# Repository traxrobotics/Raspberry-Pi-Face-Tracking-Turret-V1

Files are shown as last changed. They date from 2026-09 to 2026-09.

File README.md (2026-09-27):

# Raspberry Pi Face Tracking Turret v1






A pan and tilt camera turret that finds your face and keeps it in the middle of the picture.
Runs on a Raspberry Pi 5 with a cheap SPI camera and two SG90 servos, all wired straight
to the Pi's header. No servo driver board, no second power supply. A Pi 4 is fine too.

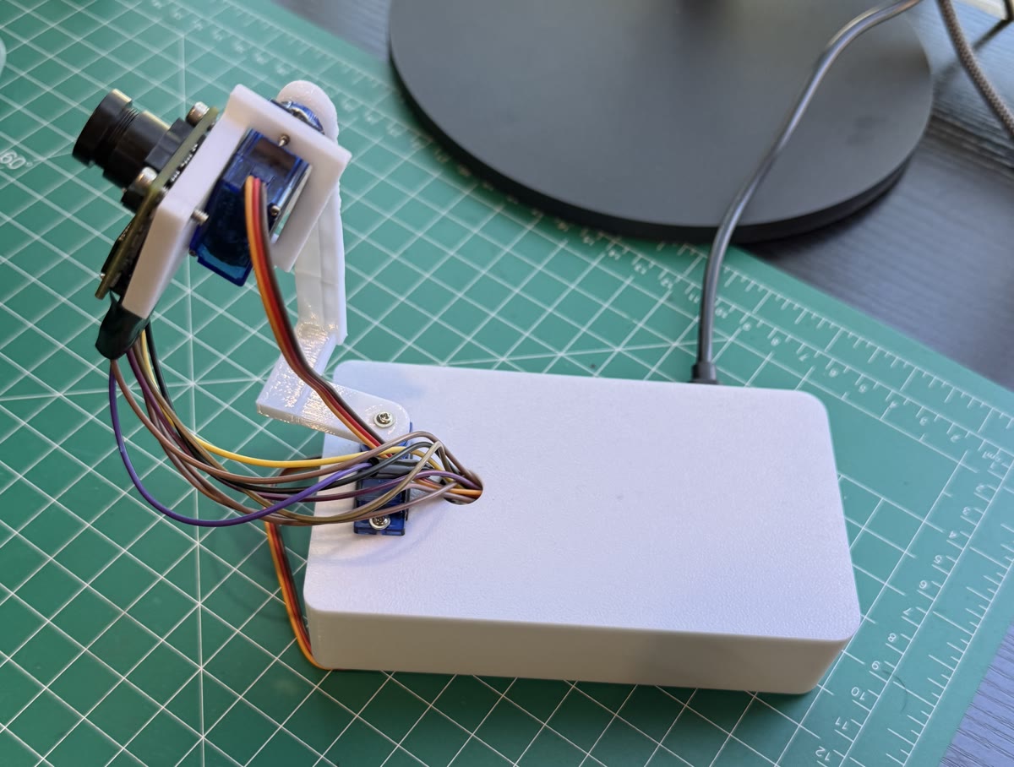
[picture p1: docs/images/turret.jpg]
The assembled turret, click to watch it tracking a face (https://www.tiktok.com/@traxrobotics/video/7688967664974302495)


The assembled turret. **[Click the photo to watch it track a face.](https://www.tiktok.com/@traxrobotics/video/7688967664974302495)**

Two clips, both on TikTok: **[building it](https://www.tiktok.com/@traxrobotics/video/7688210893309562142)**
and **[tracking a face](https://www.tiktok.com/@traxrobotics/video/7688967664974302495)**.
Both are short montages rather than tutorials, and both show the physical side
only -- no terminal, no setup steps. Those are in this README and in
[`docs/`](docs/).

<!-- A looping demo.gif at docs/images/demo.gif would play inline here;
     GitHub strips video embeds, so the photo above links out instead. -->

## Features

* **Fast, smooth tracking.** Servos run their own 100 Hz motion loop with speed and braking
  limits, so they glide instead of jerking between camera frames.
* **Aims ahead of a moving face.** It measures how fast you are moving and leads you, so it
  keeps up instead of trailing behind.
* **Chases a head that flicks out of the picture.** If your face vanishes at the edge, or while
  moving fast, or leaves a blur behind as it goes, the turret turns hard that way at once.
* **Searches when you leave.** With nobody in view it sweeps slowly side to side, first
  toward the side you walked off to, and locks back on the moment it sees a face.
* **Good face detection.** Uses YuNet (OpenCV 4.8+) or an SSD model on older OpenCV, and falls
  back to Haar only if the models are missing.
* **Fixes a sideways or upside down camera by itself**, and tells you the setting to save.
* **Live view in any browser** with the detected face boxed in green.
* **Starts on boot** as a system service, with a `turret` command to start, stop and diagnose it.
* **Plain language errors.** Every failure says which pin or setting to check.
* **Tested without hardware.** A fake camera and fake servos run the whole tracker in CI.

## Hardware

| Part | Notes |
|---|---|
| Raspberry Pi 5 | Raspberry Pi OS Bookworm or Trixie |
| ArduCAM Mini 2MP Plus (B0067) | OV2640 sensor, SPI + I2C |
| 2 × SG90 micro servos | pan and tilt |
| Pan and tilt bracket | any SG90 bracket works, or print the one in [`hardware/`](hardware/) |
| 8 × female to female jumpers | camera |
| 6 × male to female jumpers | servos |
| 1000 µF electrolytic capacitor, 10 V+ | across one servo's power, stops brownout resets |

### Printed parts

Three printable parts are in [`hardware/`](hardware/) if you would rather print the
bracket than buy one: the base, the arm, and the camera attachment. Each comes as
`.3mf` to print and `.step` to edit.

The base has no floor. That keeps the servo and wiring reachable while you build,
and lets the turret bolt onto another robot's deck instead of carrying its own
bottom plate. See [`hardware/README.md`](hardware/README.md) for print settings.

## Wiring

| Wire | Pi pin |
|---|---|
| Camera VCC | 1 (3.3 V, **never 5 V**) |
| Camera SDA / SCL | 3 / 5 |
| Camera CS | 11 (GPIO17) |
| Camera MOSI / MISO / SCK | 19 / 21 / 23 |
| Camera GND | 25 |
| Pan servo signal / 5 V / GND | 32 (GPIO12) / 2 / 34 |
| Tilt servo signal / 5 V / GND | 33 (GPIO13) / 4 / 30 |

Full diagram, reasons for each pin, and assembly order: [docs/wiring.md](docs/wiring.md).

## Quick start

On the Pi:

```bash
git clone https://github.com/traxrobotics/Raspberry-Pi-Face-Tracking-Turret-V1.git ~/turret
cd ~/turret
bash setup.sh          # packages, SPI, I2C, hardware PWM
bash install_boot.sh   # start on boot + password free 'turret' command
sudo reboot
```

After the reboot, stop the background turret so the checks can use the camera, then run them in order:

```bash
turret stop
python3 test_bus.py             # camera wiring: both lines should say OK
python3 test_capture.py         # takes snapshot.jpg and measures frame rate
python3 test_servos.py          # sweeps servos, prints PAN_DIR / TILT_DIR for config.py
python3 tracker.py --no-servos  # track without moving, open the printed address in a browser
turret start                    # track for real
```

## The `turret` command

| Command | What it does |
|---|---|
| `turret status` | is it running? |
| `turret log` | watch what it is doing (Ctrl+C stops watching, not the turret) |
| `turret stop` / `start` / `restart` | control the background service |
| `turret run` | run it in this window to see everything it prints |
| `turret boot-off` / `boot-on` | stop or resume starting on boot |
| `turret doctor` | checks every piece and says exactly what is wrong |

## Settings

Everything lives in [`config.py`](config.py). The ones you are most likely to touch:

| Setting | Default | What it does |
|---|---|---|
| `PAN_DIR`, `TILT_DIR` | from `test_servos.py` | flip if it turns away from you |
| `SERVO_SPEED` | 550 | top speed, degrees per second |
| `SERVO_ACCEL` | 4500 | how hard it speeds up and brakes |
| `CHASE` | True | turn hard toward a face that just left the picture |
| `CHASE_DEG`, `CHASE_S` | 20, 0.7 | how far past the last sighting to aim, and for how long |
| `LEAD` | 1.0 | aim ahead of a moving face, 0 turns it off |
| `SWEEP` | True | search side to side when nobody is there, False waits at center |
| `SWEEP_SPEED` | 30 | search speed, degrees per second |
| `SWEEP_MIN`, `SWEEP_MAX`, `SWEEP_TILT` | 40, 140, 90 | where it searches |
| `RETURN_AFTER_S` | 2.0 | seconds with no face before it starts searching |
| `CORRECTION` | 0.9 | lower if it swings past you |
| `SPI_SPEED_HZ` | 8 MHz | drops to 4 MHz by itself if frames fail |

Symptom by symptom tuning guide: [docs/tuning.md](docs/tuning.md).

## How it works

Three loops run at once:

1. **Camera thread** grabs JPEG frames over SPI and timestamps each one.
2. **Main loop** finds the face, works out how many degrees off center it is, checks where
   the servos were pointing when that photo was taken, and sets a new aim point, a little
   ahead of you if you are moving.
3. **Servo loop** runs 100 times a second and glides both servos toward the aim point with
   smooth acceleration.

If the face vanishes near an edge, while moving fast, or leaving a blur trail in the picture,
the turret chases: it aims past the last sighting in that direction at full speed. If that
misses, it starts sweeping that way right away.

When nobody has been seen for 2 seconds, the aim point becomes the end of a slow sweep,
and the servo loop is told to cap its speed so the camera can still spot a face mid sweep.

More detail: [docs/how-it-works.md](docs/how-it-works.md).

## Project layout

```
tracker.py        main program: detection, aiming, live view
servo.py          hardware PWM servos and the smooth motion loop
arducam.py        ArduCAM Mini 2MP Plus driver for the Pi 5 (SPI + I2C)
ov2640_regs.py    sensor register tables
config.py         every setting
test_bus.py       hardware check: camera wiring
test_capture.py   hardware check: picture and frame rate
test_servos.py    hardware check: servo range and direction
setup.sh          one time install
install_boot.sh   start on boot + turret command
turret            the turret command
doctor.sh         turret doctor
models/           face detection models
tests/            automatic tests with fake hardware (no Pi needed)
docs/             wiring, tuning, troubleshooting, internals
```

## Running the tests

No Pi needed:

```bash
pip install -r requirements-dev.txt
pytest
```

The `test_*.py` files in the top folder are hardware checks for the Pi. The automatic
tests live in `tests/` and use a fake camera and fake servos.

**One test is known to be flaky.** `test_turret_centers_on_the_face_and_settles`
fails roughly one run in four, with "turret ran away from the face". It is not
your machine and it is not a broken checkout: the fake camera produces a frame
every 30 ms while the servos run their own 100 Hz loop on the real clock, so how
far they turn between frames depends on how busy the machine is. On a loaded one
they overrun the face and the assertion fires. Re-run `pytest` and it passes.

Worth knowing rather than hiding, because it is pointing at something real: when
frames arrive slowly, the tracker overshoots. On a Pi that is fast enough to keep
the frame rate up you will not see it.

## Roadmap

* **OLED eyes.** A 0.96" SSD1306 screen showing cartoon eyes that follow your face, blink,
  and look around while the turret searches. It can share the camera's I2C bus (it sits at
  address 0x3C, the camera at 0x30). Planned, not built yet.

## Troubleshooting

Run `turret doctor` first. It checks every piece and prints the fix.
Common problems and fixes: [docs/troubleshooting.md](docs/troubleshooting.md).

## License

MIT. See [LICENSE](LICENSE). The face detection models in `models/` keep their own
licenses, listed in [NOTICE](NOTICE) and in [models/README.md](models/README.md).

## Author

Built by **Veer Sharma** ([@traxrobotics](https://www.tiktok.com/@traxrobotics)).
More projects, parts lists and code at [traxlinks.netlify.app](https://traxlinks.netlify.app).

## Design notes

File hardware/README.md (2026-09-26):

# Printed parts

Three parts make the pan and tilt stack. Everything is small, flat-ish and
prints without a heated chamber.

| Part | Carries | Files |
|---|---|---|
| `base` | the pan servo | `base.3mf`, `base.step` |
| `turret-arm` | rides the pan servo, holds the tilt servo | `turret-arm.3mf`, `turret-arm.step` |
| `camera-attachment` | the ArduCAM Mini 2MP Plus on the tilt servo | `camera-attachment.3mf`, `camera-attachment.step` |

You do not need these. The README lists "any SG90 bracket works", and that is
still true. These are here if you would rather print the exact thing in the
photos than buy a bracket.

## The base has no floor

This is deliberate, and it is the one thing worth knowing before you print.

Leaving the bottom open means you can reach the servo and the wiring while you
are working, instead of assembling blind through a hole. It also means the
turret bolts straight onto another robot's deck and uses that as its floor,
rather than carrying a redundant bottom plate of its own.

If you want it to stand on a desk by itself, print any flat plate wider than
the base and screw it on, or weigh the base down. It is not tippy, but it is
not bolted to anything either.

## Which file to use

**`.3mf` to print.** Load it straight into your slicer. These carry their units
(millimetres), so nothing arrives at 25× scale the way a bare STL sometimes does.

**`.step` to change.** STEP is solid geometry rather than a mesh, so you can open
it in Fusion, FreeCAD, Onshape or SolidWorks and actually edit it — widen the
servo pocket, move a screw hole, fit the base to your own robot. Editing a 3MF
means pushing triangles around, which you do not want to do.

There are no STL files here on purpose. 3MF does everything STL does and carries
units as well, and every current slicer reads it.

## Print settings

Standard PLA settings are fine:

| Setting | Value |
|---|---|
| Material | PLA |
| Layer height | 0.2 mm |
| Infill | 20% |
| Supports | where your slicer asks for them |

**Use PETG for the support interface if you have a multi-material setup.** PETG
does not bond well to PLA, so PETG supports snap off a PLA part cleanly and
leave a much better surface than PLA-on-PLA, which fuses and tears. This needs
an AMS, an MMU or a manual filament swap at the right layer — if you have a
single-extruder printer, just use normal PLA supports and clean them up.

Nothing here is under real load. The servos are the weak point long before the
plastic is, so there is no reason to reach for a tougher material unless the
turret is living somewhere hot.

## Assembly

Two SG90 servos and the camera, in the order in the table above: pan servo into
the base, arm onto the pan servo's horn, tilt servo into the arm, camera
attachment onto the tilt servo's horn.

Wiring is in [`../docs/wiring.md`](../docs/wiring.md). Read the 3.3 V warning at
the top of that file before you plug the camera in.

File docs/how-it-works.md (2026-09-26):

# How it works

## The camera (`arducam.py`)

The ArduCAM Mini 2MP Plus has two parts. The OV2640 sensor is set up over I2C (address 0x30).
The ArduChip stores each JPEG frame in a 384 KB buffer and hands it over on SPI.

ArduCAM's own library does not support the Pi 5, so `arducam.py` follows the same steps
using the normal Linux `spidev` and `smbus2` drivers. Chip select is driven by hand on GPIO17
so it stays low for a whole burst read. The driver cuts the real JPEG out of the buffer by
its start (`FF D8`) and end (`FF D9`) markers, because the buffer starts with a junk byte and
ends with padding. Each frame gets a timestamp for the moment the photo was taken.

## Three loops

```
 camera thread            main loop                       servo loop (100 Hz)
 ─────────────            ─────────                       ───────────────────
 take photo ──frame──▶ find face                          glide toward aim point
 timestamp it          degrees off center                 speed up, cruise, brake
 repeat                where were servos at photo time? ◀── position history
                       how fast is the face moving?
                       new aim point ─────────────────────▶ set_target
```

**Camera thread.** Pulling a frame over SPI is the slowest step. Doing it in its own thread
means the next photo is already on its way while the last one is searched, which gives more
frames per second and fresher frames. If frames keep failing at 8 MHz it drops the SPI clock
to 4 MHz by itself.

**Main loop.** The lens sees about 60° across, so a face 40 pixels off center is a known
number of degrees off. The servos keep moving while a photo is being taken and searched, so
the aim is *where the servos were when the photo was taken*, plus that angle. Using the servo
position at photo time, not the current one, is what stops it from overshooting.

**Leading a moving face.** The main loop fits a straight line through the face's position
over the last 0.4 seconds to get its speed in degrees per second. The face has already moved
on since the photo was taken, so the aim is pushed ahead by speed × (photo age + servo catch
up time), capped at 12°. Speeds under 8°/s count as sitting still, so a box that wobbles by a
pixel never causes twitching. While the servos themselves are snapping fast, their position
at photo time is too uncertain to judge speed from, so leading pauses until they slow down.

**Servo loop.** 100 times a second, each servo moves toward its aim with a trapezoid speed
profile: speed up at `SERVO_ACCEL`, cruise at `SERVO_SPEED`, and brake just in time to land
exactly on target. This keeps motion smooth even though new aim points only arrive about
12 times a second.

## Chasing a face that just left

A head moved fast enough blurs out of the picture in one or two frames. When the face
vanishes, the tracker asks three questions about its last sighting, in order:

1. **Was it moving fast?** Speed from the 0.4 s fit, or from the jump between the last two
   sightings (a sudden flick often shows up in just one frame). Over 25°/s counts.
2. **Was it near the edge?** Face center in the outer part of the picture.
3. **Did something smear away?** `motion_hint` compares a tiny 80×60 grey copy of this frame
   with the one before and finds the middle of the changed pixels. A flicked head leaves its
   blur on the side it went. Only left/right is used: the body sits below the face, so the
   changed area always leans down. If under 0.4% or over 40% of the picture changed (nothing,
   or a light/exposure change), the hint is ignored.

The first clear answer gives the direction. The turret aims `CHASE_DEG` (more if the face was
fast) past the last sighting at full speed. If nothing turns up within `CHASE_S`, it starts
sweeping that way at once instead of waiting.

To stop chases from bouncing back and forth, a chase only starts from a sighting taken
while the servos were fairly still, after the face had been tracked for at least 0.3 s, and
not within 1.5 s of the last chase. A face that vanishes from the middle with none of the
three clues (someone turning away) gets the normal wait, then the sweep.

## Searching

After `RETURN_AFTER_S` seconds with no face, the tracker switches to a sweep. It aims at one
end of the sweep (`SWEEP_MIN` or `SWEEP_MAX`), starting with the side the face was last seen
on, and asks the servo loop to cap its speed at `SWEEP_SPEED` for that move. When the servos
get within 2° of that end, it aims at the other end. Tilt holds at `SWEEP_TILT`.

The speed cap matters: at full speed the camera would smear past a face between frames.
At 30°/s and about 12 frames a second the view moves under 3° per frame, so a face is in view
for about 20 frames on every pass. The moment a face is found, the cap is lifted and normal
tracking takes over at full speed.

## Face detection

`FaceDetector` picks the best model the Pi can run:

| Detector | Needs | Notes |
|---|---|---|
| YuNet | OpenCV 4.8+ (Raspberry Pi OS Trixie) | small, fast, handles angles and dim light |
| SSD (res10) | any OpenCV 4 (Bookworm) | very reliable, a bit slower |
| Haar | nothing | last resort if `models/` is missing |

When there are several faces it sticks with the one closest to the face it was already
following, so it does not jump between people.

## Auto orientation

A face detector is always most confident about an upright face. `AutoOrient` scores the
picture as is and turned 90°, 180° and 270°, and keeps whichever it is surest about. The
servos hold still until the check passes, so they never chase an upside down face (which
would make the turret run away). Once the picture keeps passing, it checks less and less
often, down to once every 320 face frames.

## Servos (`servo.py`)

Hardware PWM through `/sys/class/pwm` at 50 Hz, 600 to 2400 µs for 0 to 180°. The PWM block's
number changes between OS versions, so it is found by name: the one at `...98000.pwm` drives
GPIO12/13. The one at `...9c000.pwm` runs the Pi 5 cooling fan and is never touched.

## Boot service

`install_boot.sh` installs a normal systemd service that runs as root (so it never trips over
permissions at boot) and restarts every 3 seconds until the camera and servos are ready. A
sudoers rule lets your user start and stop exactly that service, and nothing else, with no
password. On stop it glides both servos to center and turns the PWM off so they go limp.

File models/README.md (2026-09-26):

# Face detection models

`tracker.py` picks the best one your OpenCV can run. Keep this folder next to `tracker.py`.

| File | Model | Source | License |
|---|---|---|---|
| `face_detection_yunet_2023mar.onnx` | YuNet | [opencv/opencv_zoo](https://github.com/opencv/opencv_zoo/tree/main/models/face_detection_yunet) | MIT, Copyright (c) 2020 Shiqi Yu |
| `res10_300x300_ssd_iter_140000.caffemodel` | ResNet 10 SSD | [opencv/opencv_3rdparty](https://github.com/opencv/opencv_3rdparty/tree/dnn_samples_face_detector_20170830) | OpenCV project, see source |
| `deploy.prototxt` | SSD network definition | [opencv/opencv samples](https://github.com/opencv/opencv/tree/4.x/samples/dnn/face_detector) | OpenCV project, see source |

These files are redistributed unchanged. They are not covered by this project's MIT license.

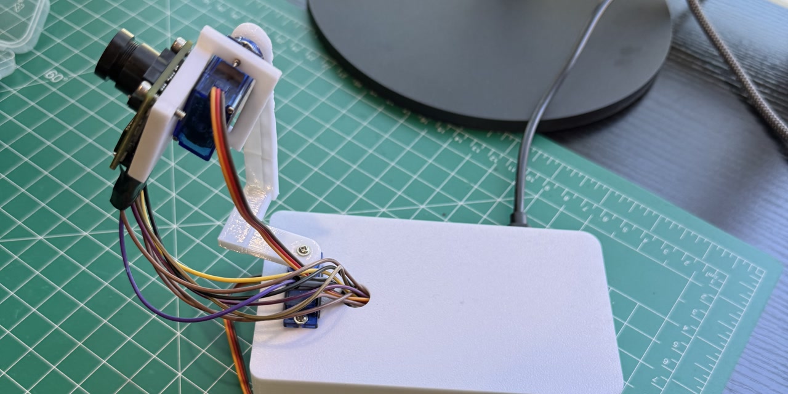
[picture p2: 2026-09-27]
docs/images/social-preview.jpg

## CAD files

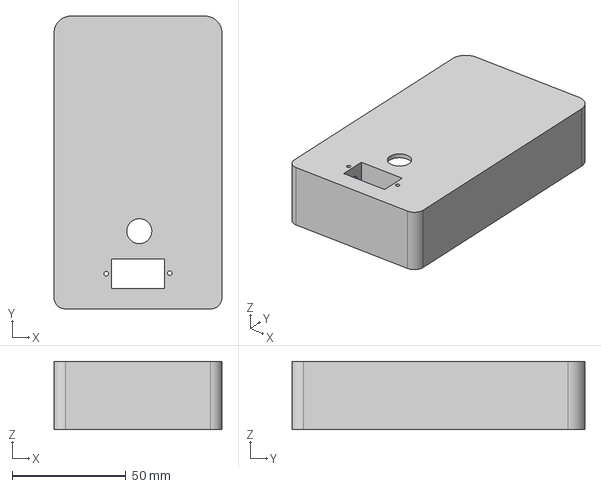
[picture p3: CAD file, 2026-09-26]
hardware/base.step
74.0 x 129.0 x 30.0 mm

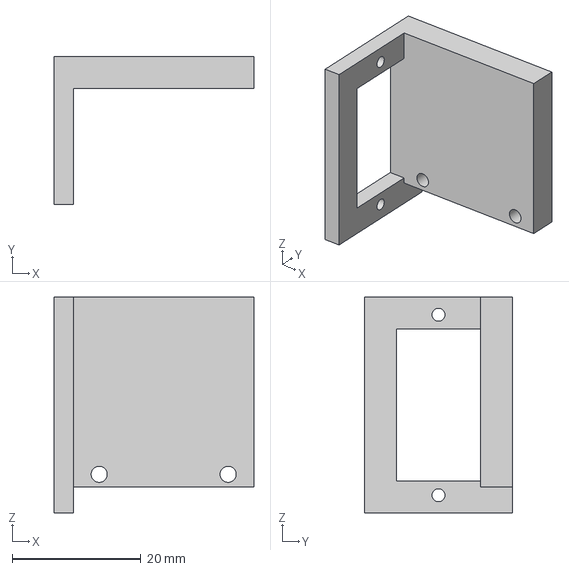
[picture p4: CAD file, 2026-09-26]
hardware/camera-attachment.step
31.0 x 23.0 x 33.5 mm

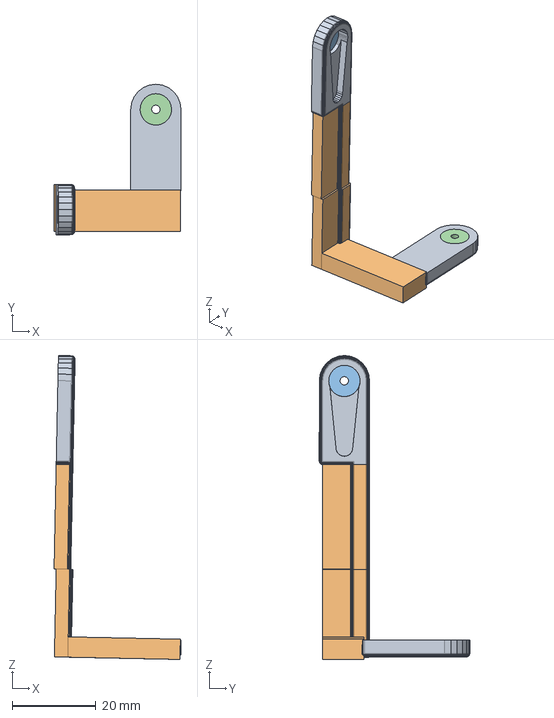
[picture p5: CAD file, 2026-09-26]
hardware/turret-arm.step
30.3 x 36.0 x 72.6 mm

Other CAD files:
hardware/base.3mf
hardware/camera-attachment.3mf
hardware/turret-arm.3mf

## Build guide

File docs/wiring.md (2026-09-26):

# Wiring

Every connection from the ArduCAM B0067 and both SG90 servos into a Raspberry Pi 5 header.
14 of 40 pins used. No breakout board, no second supply.

> **Camera VCC goes to 3.3 V (pin 1). Never 5 V (pin 2).**
> The camera runs on either, but its output pins swing to whatever it is fed. The Pi's GPIO
> is not 5 V tolerant, so a camera on 5 V pushes 5 V back into the Pi on MISO and kills pins.
> Pin 1 and pin 2 sit right next to each other. Get this one right.

## Header map

Pin 1 is the inner row, at the end away from the USB ports. It has the only square solder pad.
Run `pinout` on the Pi to see it drawn.

```
                 3.3V  CAM VCC   1 ● ● 2   5V    PAN V+
            GPIO2      CAM SDA   3 ● ● 4   5V    TILT V+
            GPIO3      CAM SCL   5 ● ○ 6
                                 7 ○ ○ 8
                                 9 ○ ○ 10
           GPIO17      CAM CS   11 ● ○ 12
                                13 ○ ○ 14
                                15 ○ ○ 16
                                17 ○ ○ 18
           GPIO10     CAM MOSI  19 ● ○ 20
            GPIO9     CAM MISO  21 ● ○ 22
           GPIO11      CAM SCK  23 ● ○ 24
                       CAM GND  25 ● ○ 26
                                27 ○ ○ 28
                                29 ○ ● 30  GND   TILT GND
                                31 ○ ● 32  GPIO12  PAN SIGNAL
           GPIO13  TILT SIGNAL  33 ● ● 34  GND   PAN GND
                                35 ○ ○ 36
                                37 ○ ○ 38
                                39 ○ ○ 40
```

## Camera, 8 wires (female to female)

| Camera pin | Pi pin | Signal |
|---|---|---|
| VCC | 1 | 3.3 V power |
| GND | 25 | ground |
| SDA | 3 | GPIO2, I2C data |
| SCL | 5 | GPIO3, I2C clock |
| CS | 11 | GPIO17, chip select |
| MOSI | 19 | GPIO10, data out |
| MISO | 21 | GPIO9, data in |
| SCK | 23 | GPIO11, SPI clock |

CS is on GPIO17 instead of the hardware chip select on pin 24. That matches ArduCAM's own
Pi reference, and lets the driver hold CS low for a whole burst read, which the hardware line
would break between transfers.

Keep these eight wires under 15 cm and use stranded wire. They flex every time the head
moves, and solid core wire work hardens and snaps at the connector. Long wires are also the
main reason frames fail at 8 MHz SPI (the tracker drops to 4 MHz by itself if that happens).

## Servos, 6 wires (male to female)

| Servo | Wire | Pi pin | What it is |
|---|---|---|---|
| Pan (base) | orange | 32 | GPIO12 signal |
| | red | 2 | 5 V |
| | brown | 34 | ground |
| Tilt (top) | orange | 33 | GPIO13 signal |
| | red | 4 | 5 V |
| | brown | 30 | ground |

The SG90's three pin plug will not fit, because the pins it needs are not next to each
other on the header. Push male to female jumpers into the servo plug instead.

**Why GPIO12 and GPIO13:** only GPIO 12, 13, 18 and 19 have hardware PWM on a Pi 5.
Any other pin is software timed and the servos buzz and jitter.

**The capacitor:** put a 1000 µF, 10 V or higher electrolytic across one servo's red and brown
wires, at the servo end, stripe to brown. Fast starts pull current spikes that can dip the
Pi's 5 V rail and reboot it. The capacitor covers those spikes.

## Assembly order

1. Pi **unplugged**. Not asleep, not shut down with power still in.
2. Find pin 1 and prove it. Count from there, twice.
3. Camera signals and ground first, VCC into pin 1 last.
4. Servo signals to 32 and 33.
5. Servo grounds to 34 and 30, then 5 V to 2 and 4.
6. Capacitor across one servo's red and brown.
7. Check every wire against the map once more before power goes on.

## Planned: OLED eyes

An SSD1306 I2C OLED can join later without new signal pins. It shares the camera's I2C bus
(it answers at 0x3C, the camera at 0x30), so SDA and SCL need a split: a Y jumper, a small
breadboard, or solder the OLED wires onto the camera's SDA/SCL jumpers.

| OLED pin | Pi pin |
|---|---|
| VCC | 17 (3.3 V, pin 1 is already taken by the camera) |
| GND | 9 |
| SDA | 3 (shared with camera) |
| SCL | 5 (shared with camera) |

After wiring, `i2cdetect -y 1` should show both 30 and 3c.

## First power on

```bash
pinout               # confirm the Pi agrees with your pin numbering
ls /dev/spidev*      # expect /dev/spidev0.0
i2cdetect -y 1       # expect 30 in the grid (the OV2640 sensor)
python3 test_bus.py  # both lines should say OK
```

If the I2C grid is empty it is almost always VCC or GND, not the data lines.
Recheck pin 1 and pin 25 first.

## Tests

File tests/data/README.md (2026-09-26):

`face.jpg` is the NASA portrait of astronaut Eileen Collins (public domain), the same image
scikit-image ships as `astronaut`. The tests use it as the face the fake camera sees.

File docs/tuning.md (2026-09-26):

# Tuning

All settings are in `config.py`. After a change, run `turret restart`.

| Problem | Change |
|---|---|
| Turret runs away from your face | flip the sign of `PAN_DIR` or `TILT_DIR` |
| Swings past your face, then comes back | `CORRECTION = 0.75` (default 0.9) |
| Stops a little short of your face | `CORRECTION = 1.0` |
| Falls behind when you walk | `LEAD = 1.3` (default 1.0) |
| Overshoots when you stop walking | `LEAD = 0.6`, or `0` to turn leading off |
| Moves too slowly | `SERVO_SPEED = 600` (default 550, SG90 tops out near here) |
| Starts and stops too sharply | `SERVO_ACCEL = 2500` (default 4500) |
| Loses you when you whip your head away | check `CHASE = True`, raise `CHASE_DEG` to 25 |
| Chases off when you only turn your head | `CHASE_DEG = 12`, or `CHASE = False` |
| Pi reboots when the servos move | add the 1000 µF cap, then `SERVO_ACCEL = 1500` |
| Twitches even when you sit still | raise `DEADZONE_X` / `DEADZONE_Y` |
| You swapped the lens | `FOV_DEG = ` its horizontal angle (stock lens is 60) |
| Camera hits the frame | tighten `TILT_MIN` / `TILT_MAX` |
| Frames keep failing | `SPI_SPEED_HZ = 4_000_000` (it also drops there by itself) |
| Low frame rate | `FRAME_SIZE = (160, 120)` |
| Misses you when you are far away | `FRAME_SIZE = (640, 480)` (slower, sees farther) |
| Locks onto things that are not faces | `FACE_SCORE = 0.75` (default 0.6 YuNet, 0.5 SSD) |
| Box flickers off too often | `HOLD_FACE_S = 1.0` (default 0.5) |
| Sweeps right past you without stopping | `SWEEP_SPEED = 20` (default 30) |
| Searches too high or too low | change `SWEEP_TILT` (default 90) |
| Hits something or pulls wires while searching | narrow `SWEEP_MIN` / `SWEEP_MAX` |
| Starts searching too soon or too late | `RETURN_AFTER_S` (default 2.0) |
| Rather it wait at center than search | `SWEEP = False` |
| Auto rotate guesses wrong | `AUTO_ROTATE = False` and set `ROTATE` yourself |

## Speed, in numbers

Measured in the built in simulator (fake camera at a realistic frame time, face jumping
25° and then walking side to side at up to about 50°/s):

| | v1.0 | v1.1 |
|---|---|---|
| Frames per second | 9.8 | 11.9 |
| Time to snap onto a face 25° away | 0.20 s | 0.13 s |
| Average aim error on a walking face | 4.7° | 1.9° |

Real numbers on your Pi depend on wire length (SPI speed) and your OpenCV version.
Watch `turret log`, it prints the frame rate every 2 seconds.

## Settings that are no longer used

`GAIN`, `MAX_STEP`, `SMOOTHING` and `ROTATE_180` from old configs are ignored
(`ROTATE_180 = True` still works and means `ROTATE = 180`). Delete them whenever you like.

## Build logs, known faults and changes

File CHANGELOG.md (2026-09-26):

# Changelog

## 1.3.0 (2026-09-24)

Chases a head that leaves the picture.

* When the face vanishes near an edge, while moving fast, or leaving a blur trail, the turret
  turns hard that way at once (`CHASE`, `CHASE_DEG`, `CHASE_S`). If that misses, it sweeps that
  way right away instead of waiting.
* Flick direction comes from the jump between the last two sightings, not just the slower
  0.4 s speed fit, so a one frame flick is caught.
* New motion hint: compares tiny grey copies of consecutive frames to see which way a blurred
  head went.
* Guards against bouncing: only chases off steady sightings, never from a blurry glimpse mid
  swing, and not twice within 1.5 s.
* Faster servo defaults: `SERVO_SPEED` 450 → 550, `SERVO_ACCEL` 3500 → 4500.
* Log and live view show "chasing".

In a still room simulation with motion blur, a head flicked 40 to 50° at up to 400°/s is back in
the middle in 0.3 to 0.8 s. Before, it often sat still for 2 s and then swept, 2.5 to 5 s total.

## 1.2.0 (2026-09-24)

Searches when you leave.

* With no face for `RETURN_AFTER_S` (now 2 s), the turret sweeps slowly side to side instead of
  waiting at center. It heads toward the side you walked off to first.
* New settings: `SWEEP`, `SWEEP_SPEED`, `SWEEP_MIN`, `SWEEP_MAX`, `SWEEP_TILT`. `SWEEP = False`
  brings back the old wait at center behavior.
* The servo loop can now cap its top speed for a single move (`set_target(..., speed=)`).
* Live view shows "searching..." and the log adds "searching" while sweeping.
* New tests, including a simulation where the face starts out of view and has to be found.

## 1.1.0 (2026-09-24)

Faster tracking.

* Camera runs in its own thread, so the next frame is captured while the last one is searched.
* Aims ahead of a moving face (`LEAD`), using its speed over the last 0.4 s.
* Deadzone only applies while you sit still, so it no longer stops and starts while following you.
* Faster servo defaults: `SERVO_SPEED` 250 → 450, `SERVO_ACCEL` 1500 → 3500.
* SPI clock 4 → 8 MHz by default, and drops back to 4 MHz by itself if frames fail.
* Live view skips drawing and JPEG encoding when nobody is watching.
* Orientation recheck backs off once the picture keeps passing.
* Automatic tests with fake hardware, run on every push by GitHub Actions.

In simulation: 9.8 → 11.9 fps, 25° snap 0.20 → 0.13 s, average error on a walking face 4.7° → 1.9°.

## 1.0.0 (2026-09-23)

First release.

* ArduCAM Mini 2MP Plus driver for the Pi 5 (SPI + I2C, no ArduCAM library needed).
* Hardware PWM servos with a 100 Hz smooth motion loop.
* YuNet / SSD / Haar face detection, picked automatically.
* Automatic fix for a sideways or upside down camera.
* Live browser view.
* Start on boot service, `turret` command and `turret doctor`.

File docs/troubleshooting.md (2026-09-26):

# Troubleshooting

Start with:

```bash
turret doctor
```

It checks the files, the boot service, SPI, I2C, the PWM overlay and your permissions,
and prints the fix for anything wrong plus the last lines of the log.

| What you see | Fix |
|---|---|
| SPI check reads 0x00 or 0xFF | MISO or VCC loose. Check pins 21 and 1. |
| Sensor did not answer on I2C | SDA pin 3, SCL pin 5, VCC pin 1, GND pin 25. |
| Only the fan PWM is present | The overlay line is missing. Check the end of `/boot/firmware/config.txt`, then reboot. |
| Servos do not move, no error | Run `pinctrl get 12,13`. Both should say PWM. If not, the overlay did not load. |
| Pi reboots when the servos move | Add the 1000 µF cap across a servo's red and brown wires, lower `SERVO_ACCEL`. |
| "Dropped to 4 MHz" in the log | Wires too long or loose for 8 MHz. Shorten them, or set `SPI_SPEED_HZ = 4_000_000`. |
| Frames fail a lot even at 4 MHz | Shorter camera wires, or `SPI_SPEED_HZ = 2_000_000`. |
| "No permission ... without sudo" | Run `bash install_boot.sh` once, then `sudo reboot`. |
| "The camera is already in use" | The background turret has it. `turret stop` first. |
| `turret: command not found` | Run `bash ~/turret/install_boot.sh` again. |
| Face detector says Haar | The `models` folder is missing. Keep it next to `tracker.py`. |
| Live view page will not load | Pi and phone on the same network? Port taken? Try `turret run` and read the output. |
| Does not start on boot | `turret doctor`. |

## Reporting a problem

Open an issue and paste the full output of `turret doctor`.

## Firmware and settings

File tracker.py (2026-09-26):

"""Track your face and move the servos to keep it in the middle of the picture.

    python3 tracker.py               # track and move
    python3 tracker.py --no-servos   # track only, servos stay still

After install_boot.sh it also runs by itself on boot. See the 'turret' command.

Watch it live in a browser at  http://<pi address>:8000
Press Ctrl+C to stop.
"""

import argparse
import math
import os
import signal
import socket
import sys
import threading
import time
from collections import deque
from http.server import BaseHTTPRequestHandler, ThreadingHTTPServer

import cv2

import config
from arducam import ArduCam, CameraError

HERE = os.path.dirname(os.path.abspath(__file__))
MODELS = os.path.join(HERE, "models")


# ---------------- picture orientation ----------------

def rotation_setting(cfg):
    """ROTATE in config.py can be 0, 90, 180 or 270. Older configs used ROTATE_180."""
    r = getattr(cfg, "ROTATE", None)
    if r is None:
        r = 180 if getattr(cfg, "ROTATE_180", False) else 0
    r = int(r) % 360
    if r not in (0, 90, 180, 270):
        sys.exit("ROTATE in config.py must be 0, 90, 180 or 270")
    return r


def rotate(frame, degrees):
    if degrees == 90:
        return cv2.rotate(frame, cv2.ROTATE_90_CLOCKWISE)
    if degrees == 180:
        return cv2.rotate(frame, cv2.ROTATE_180)
    if degrees == 270:
        return cv2.rotate(frame, cv2.ROTATE_90_COUNTERCLOCKWISE)
    return frame


def orient(frame, cfg):
    frame = rotate(frame, rotation_setting(cfg))
    if getattr(cfg, "MIRROR", False):
        frame = cv2.flip(frame, 1)
    return frame


# ---------------- face detector ----------------

def opencv_version():
    parts = cv2.__version__.split(".")
    return int(parts[0]), int(parts[1])


class FaceDetector:
    """Picks the best detector this Pi can run.

    YuNet    needs OpenCV 4.8 or newer. Small, fast, handles angles and dim light.
    SSD      works on any OpenCV 4. Very reliable, a bit slower.
    Haar     last resort if the model files are missing. Misses a lot.
    """

    def __init__(self, score=None):
        yunet = os.path.join(MODELS, "face_detection_yunet_2023mar.onnx")
        proto = os.path.join(MODELS, "deploy.prototxt")
        caffe = os.path.join(MODELS, "res10_300x300_ssd_iter_140000.caffemodel")
        self.kind = None
        self.input_size = None

        if opencv_version() >= (4, 8) and hasattr(cv2, "FaceDetectorYN") and os.path.exists(yunet):
            try:
                self.score = 0.6 if score is None else score
                self.yunet = cv2.FaceDetectorYN.create(yunet, "", (320, 240), self.score, 0.3, 50)
                self.kind = "YuNet"
            except cv2.error:
                self.kind = None

        if self.kind is None and os.path.exists(proto) and os.path.exists(caffe):
            self.score = 0.5 if score is None else score
            self.ssd = cv2.dnn.readNetFromCaffe(proto, caffe)
            self.kind = "SSD"

        if self.kind is None:
            self.score = 0
            self.haar = self._load_haar()
            self.clahe = cv2.createCLAHE(clipLimit=2.0, tileGridSize=(8, 8))
            self.kind = "Haar (weak, the models folder is missing)"

    @staticmethod
    def _load_haar():
        paths = []
        if hasattr(cv2, "data"):
            paths.append(os.path.join(cv2.data.haarcascades, "haarcascade_frontalface_default.xml"))
        paths += ["/usr/share/opencv4/haarcascades/haarcascade_frontalface_default.xml",
                  "/usr/share/opencv/haarcascades/haarcascade_frontalface_default.xml"]
        for p in paths:
            if os.path.exists(p):
                det = cv2.CascadeClassifier(p)
                if not det.empty():
                    return det
        sys.exit("No face model found. Put the models folder next to tracker.py.")

    def detect(self, frame):
        """Returns a list of (x, y, w, h, score) in pixels."""
        h, w = frame.shape[:2]

        if self.kind == "YuNet":
            if self.input_size != (w, h):
                self.yunet.setInputSize((w, h))
                self.input_size = (w, h)
            _, faces = self.yunet.detect(frame)
            if faces is None:
                return []
            return [(float(f[0]), float(f[1]), float(f[2]), float(f[3]), float(f[-1])) for f in faces]

        if self.kind == "SSD":
            blob = cv2.dnn.blobFromImage(cv2.resize(frame, (300, 300)), 1.0, (300, 300), (104.0, 177.0, 123.0))
            self.ssd.setInput(blob)
            out = self.ssd.forward()[0, 0]
            found = []
            for det in out:
                conf = float(det[2])
                if conf < self.score:
                    continue
                x1, y1 = max(0.0, det[3] * w), max(0.0, det[4] * h)
                x2, y2 = min(w - 1.0, det[5] * w), min(h - 1.0, det[6] * h)
                if x2 - x1 > 4 and y2 - y1 > 4:
                    found.append((x1, y1, x2 - x1, y2 - y1, conf))
            return found

        gray = self.clahe.apply(cv2.cvtColor(frame, cv2.COLOR_BGR2GRAY))
        faces = self.haar.detectMultiScale(gray, scaleFactor=1.1, minNeighbors=4, minSize=(24, 24))
        return [(float(x), float(y), float(fw), float(fh), 1.0) for x, y, fw, fh in faces]


def pick_face(faces, previous):
    """Stick with the same person. If we were already following someone, take the
    face closest to where they were. Otherwise take the biggest, surest face."""
    if not faces:
        return None
    if previous is not None:
        px, py = previous
        return min(faces, key=lambda f: math.hypot(f[0] + f[2] / 2 - px, f[1] + f[3] / 2 - py))
    return max(faces, key=lambda f: f[2] * f[3] * f[4])


# ---------------- tracking math ----------------

MOTION_SIZE = (80, 60)


def small_gray(frame):
    """Tiny grey copy of a frame, for spotting motion cheaply."""
    return cv2.resize(cv2.cvtColor(frame, cv2.COLOR_BGR2GRAY), MOTION_SIZE, interpolation=cv2.INTER_AREA)


def motion_hint(before, after, face_x, face_y, width, height):
    """Which way did things move between two frames, compared to where the face was?

    A head flicked out of the picture too fast to detect still leaves a smear of changed
    pixels on the side it went. Returns (dx, dy) in picture pixels from the last face
    center to the middle of the changed area, or None if hardly anything changed.
    """
    if before is None or after is None or face_x is None:
        return None
    changed = cv2.threshold(cv2.absdiff(before, after), 25, 255, cv2.THRESH_BINARY)[1]
    m = cv2.moments(changed, binaryImage=True)
    if m["m00"] < changed.size * 0.004:        # under 0.4% of the picture changed
        return None
    if m["m00"] > changed.size * 0.4:          # most of it changed: a light or the exposure, not a head
        return None
    sx, sy = width / MOTION_SIZE[0], height / MOTION_SIZE[1]
    return m["m10"] / m["m00"] * sx - face_x, m["m01"] / m["m00"] * sy - face_y


class Tracker:
    """Works out where the servos should aim so your face ends up in the middle.

    The lens sees FOV_DEG degrees across the picture, so a face 40 pixels off
    center is a known number of degrees off. The aim is: where the servos were
    when the photo was taken, plus that angle. One frame is enough to get most of
    the way there, then the ServoMover glides there smoothly.

    If the face is moving, it also aims a little ahead of it (LEAD in config.py),
    so the turret keeps up instead of always trailing behind.

    If the face vanishes near the edge of the picture, or while moving fast, it
    chases: turns hard toward where the face must have gone (CHASE in config.py).
    If that does not find it, it starts sweeping that way right away.

    With no face for RETURN_AFTER_S seconds it goes looking: a slow sweep side to
    side (SWEEP in config.py), starting toward the side the face left from.
    """

    def __init__(self, cfg):
        self.cfg = cfg
        self.fov = float(getattr(cfg, "FOV_DEG", 60.0))
        self.correction = float(getattr(cfg, "CORRECTION", 0.9))
        self.lead = float(getattr(cfg, "LEAD", 1.0))
        self.pan = float(cfg.PAN_CENTER)      # current aim
        self.tilt = float(cfg.TILT_CENTER)
        self.face_x = None                    # last face center, for drawing
        self.face_y = None
        self.last_seen = time.monotonic()
        self._seen = deque()                  # recent (photo time, face pan angle, face tilt angle)
        self.vel_pan = 0.0                    # how fast the face is moving, degrees per second
        self.vel_tilt = 0.0

        # searching when nobody is in the picture
        self.sweep = bool(getattr(cfg, "SWEEP", True))
        self.sweep_speed = float(getattr(cfg, "SWEEP_SPEED", 30.0))
        self.sweep_min = max(cfg.PAN_MIN, float(getattr(cfg, "SWEEP_MIN", cfg.PAN_MIN)))
        self.sweep_max = min(cfg.PAN_MAX, float(getattr(cfg, "SWEEP_MAX", cfg.PAN_MAX)))
        self.sweep_tilt = float(getattr(cfg, "SWEEP_TILT", cfg.TILT_CENTER))
        self.sweeping = False
        self.sweep_dir = 1                    # +1 toward sweep_max, -1 toward sweep_min
        self.last_side = 0                    # which way the face was off center when last seen
        self.speed_limit = None               # slower top speed for the servos, None = full speed

        # chasing a face that just left the picture
        self.chase = bool(getattr(cfg, "CHASE", True))
        self.chase_deg = float(getattr(cfg, "CHASE_DEG", 20.0))
        self.chase_s = float(getattr(cfg, "CHASE_S", 0.7))
        self.chasing = False
        self.chased = False                   # a chase already ran for this loss
        self.lost = False                     # the face is currently missing
        self.last_ang = None                  # where the face really was when last seen (pan, tilt)
        self.last_photo = None                # photo time of that sighting
        self.jump = (0.0, 0.0)                # speed between the last two sightings, degrees per second
        self.last_servo_speed = 0.0           # how fast the servos moved at the last sighting
        self.streak_start = None              # when the current unbroken run of sightings began
        self.last_chase = -1e9                # when the last chase started
        self.last_edge = (0, 0)               # was it near the left/right, top/bottom edge

    FAST_SERVO = 150.0        # degrees per second. While the servos move faster than this,
                              # where they pointed at photo time is too uncertain to judge speed
    SPEED_WINDOW_S = 0.4      # judge the face's speed over this much recent time
    SPEED_MIN_SPAN_S = 0.15   # need at least this much to trust it

    def _track_speed(self, when, ang_pan, ang_tilt):
        """Work out how fast the face is moving across the room, in degrees per second.

        Uses a straight line fit over the last 0.4 s instead of just two frames, so
        a box that wobbles by a pixel or two does not look like movement.
        """
        seen = self._seen
        if seen and when - seen[-1][0] > 0.5:
            seen.clear()                   # long gap, old samples mean nothing now
        seen.append((when, ang_pan, ang_tilt))
        while seen and when - seen[0][0] > self.SPEED_WINDOW_S:
            seen.popleft()
        if len(seen) < 3 or seen[-1][0] - seen[0][0] < self.SPEED_MIN_SPAN_S:
            self.vel_pan = self.vel_tilt = 0.0
            return
        t_avg = sum(s[0] for s in seen) / len(seen)
        p_avg = sum(s[1] for s in seen) / len(seen)
        q_avg = sum(s[2] for s in seen) / len(seen)
        tt = sum((s[0] - t_avg) ** 2 for s in seen)
        self.vel_pan = sum((s[0] - t_avg) * (s[1] - p_avg) for s in seen) / tt
        self.vel_tilt = sum((s[0] - t_avg) * (s[2] - q_avg) for s in seen) / tt

    def _lead(self, vel, ahead):
        """How far ahead of the face to aim. Ignores tiny speeds, those are just jitter."""
        if abs(vel) < self.MIN_LEAD_SPEED:
            return 0.0
        return max(-self.MAX_LEAD_DEG, min(self.MAX_LEAD_DEG, vel * ahead))

    MIN_LEAD_SPEED = 8.0      # degrees per second. Slower than this is treated as sitting still
    MAX_LEAD_DEG = 12.0       # never aim more than this far ahead of the face
    SERVO_CATCH_UP_S = 0.08   # extra time the servos need to get where they are sent

    EDGE_FRAC = 0.45          # face center this far from the middle toward an edge = "near the edge"
    CHASE_SPEED = 25.0        # degrees per second. A face moving faster than this and then gone = chase

    def _chase_dir(self, vel, edge):
        if abs(vel) >= self.CHASE_SPEED:
            return 1 if vel > 0 else -1
        return edge

    @staticmethod
    def _faster(a, b):
        return a if abs(a) >= abs(b) else b

    def _motion_dirs(self, motion, width, height):
        """Direction from the motion hint. Left/right only: your shoulders and body sit below
        your face, so the changed area always leans downward and up/down cannot be trusted."""
        if motion is None:
            return 0, 0
        dx = motion[0] / width                # as a share of the picture width
        if abs(dx) > 0.04:
            return (self.cfg.PAN_DIR if dx > 0 else -self.cfg.PAN_DIR), 0
        return 0, 0

    STEADY_S = 0.3            # the face must have been tracked this long for its last sighting to be trusted

    def _start_chase(self, now, motion=None, width=320, height=240):
        """The face just vanished. If it left over an edge or was moving fast, go after it.

        Speed comes from the smooth 0.4 s estimate or, for a sudden flick that only
        shows up in the very last frame, from the jump between the last two sightings.
        """
        # Only trust the last sighting if the turret was fairly still and had been
        # following the face for a moment. Otherwise a blurry glimpse mid swing could send
        # it the wrong way, and chases would bounce back and forth.
        if self.last_servo_speed >= self.FAST_SERVO:
            return
        if self.streak_start is None or self.last_seen - self.streak_start < self.STEADY_S:
            return
        if now - self.last_chase < 1.5:
            return
        vp = self._faster(self.vel_pan, self.jump[0])
        vt = self._faster(self.vel_tilt, self.jump[1])
        dp = self._chase_dir(vp, self.last_edge[0])
        dt = self._chase_dir(vt, self.last_edge[1])
        if dp == 0 and dt == 0:               # vanished with no other clue: follow the smear
            dp, dt = self._motion_dirs(motion, width, height)
        if not self.chase or self.last_ang is None or (dp == 0 and dt == 0):
            return
        # Aim past where it was last seen, further if it was moving fast.
        extra_p = max(self.chase_deg, min(40.0, abs(vp) * 0.2))
        extra_t = max(self.chase_deg * 0.6, min(25.0, abs(vt) * 0.2))
        self.pan = self.last_ang[0] + dp * extra_p if dp else self.pan
        self.tilt = self.last_ang[1] + dt * extra_t if dt else self.tilt
        if dp:
            self.last_side = dp               # if the chase misses, sweep this way
        self.chasing = self.chased = True
        self.last_chase = now
        self.speed_limit = None

    def _sweep_step(self, pan_now):
        """Nobody in the picture: pan slowly from side to side until a face shows up."""
        if not self.sweeping:
            self.sweeping = True
            self.sweep_dir = self.last_side or 1      # first look where you walked off to
        end = self.sweep_max if self.sweep_dir > 0 else self.sweep_min
        if (pan_now - end) * self.sweep_dir >= -2.0:  # reached this end, turn around
            self.sweep_dir = -self.sweep_dir
            end = self.sweep_max if self.sweep_dir > 0 else self.sweep_min
        self.pan, self.tilt = end, self.sweep_tilt
        self.speed_limit = self.sweep_speed

    def update(self, face, width, height, pan_at_photo, tilt_at_photo, now=None, photo_time=None,
               servo_speed=0.0, motion=None):
        cfg = self.cfg
        now = time.monotonic() if now is None else now
        photo_time = now if photo_time is None else photo_time

        if face is not None:
            x, y, w, h = face[:4]
            fx, fy = x + w / 2.0, y + h / 2.0
            self.face_x, self.face_y = fx, fy
            deg_per_px = self.fov / max(width, height)   # the 60 degrees span the long side
            err_x = fx - width / 2.0      # + means face is right of center
            err_y = fy - height / 2.0     # + means face is below center

            off_pan = cfg.PAN_DIR * err_x * deg_per_px       # degrees from where the camera pointed
            off_tilt = cfg.TILT_DIR * err_y * deg_per_px

            # Where the face really was when the photo was taken. Used to judge its speed.
            if servo_speed < self.FAST_SERVO:
                self._track_speed(photo_time, pan_at_photo + off_pan, tilt_at_photo + off_tilt)
            else:
                self._seen.clear()        # mid snap: the turret is already moving fast, no lead needed
                self.vel_pan = self.vel_tilt = 0.0

            # Where to aim: at the face (CORRECTION < 1 stops a little short, so it never
            # swings past), plus a little ahead if the face is moving, because it has
            # already moved on since the photo was taken.
            if abs(off_pan) > 1.0:
                self.last_side = 1 if off_pan > 0 else -1
            self.sweeping = False
            self.speed_limit = None
            if self.lost or self.streak_start is None:
                self.streak_start = now
            self.chasing = self.chased = self.lost = False
            ang = (pan_at_photo + off_pan, tilt_at_photo + off_tilt)
            steady = servo_speed < self.FAST_SERVO and self.last_servo_speed < self.FAST_SERVO
            if steady and self.last_ang is not None and self.last_photo is not None \
                    and 0.02 < photo_time - self.last_photo < 0.3:
                gap = photo_time - self.last_photo
                self.jump = ((ang[0] - self.last_ang[0]) / gap, (ang[1] - self.last_ang[1]) / gap)
            else:
                self.jump = (0.0, 0.0)
            self.last_ang, self.last_photo = ang, photo_time
            self.last_servo_speed = servo_speed
            edge_x = err_x / (width / 2.0)            # -1 left edge .. +1 right edge
            edge_y = err_y / (height / 2.0)
            self.last_edge = (
                (cfg.PAN_DIR if edge_x > 0 else -cfg.PAN_DIR) if abs(edge_x) > self.EDGE_FRAC else 0,
                (cfg.TILT_DIR if edge_y > 0 else -cfg.TILT_DIR) if abs(edge_y) > self.EDGE_FRAC else 0,
            )

            ang_pan = pan_at_photo + off_pan * self.correction
            ang_tilt = tilt_at_photo + off_tilt * self.correction
            ahead = self.lead * (min(0.3, max(0.0, now - photo_time)) + self.SERVO_CATCH_UP_S)

            # The deadzone stops twitching while you sit still. While you move it is
            # ignored, otherwise the turret would stop every time it caught up.
            if abs(err_x) > cfg.DEADZONE_X or abs(self.vel_pan) >= self.MIN_LEAD_SPEED:
                self.pan = ang_pan + self._lead(self.vel_pan, ahead)
            if abs(err_y) > cfg.DEADZONE_Y or abs(self.vel_tilt) >= self.MIN_LEAD_SPEED:
                self.tilt = ang_tilt + self._lead(self.vel_tilt, ahead)
            self.last_seen = now

        else:
            if not self.lost:
                self.lost = True
                self._start_chase(now, motion, width, height)   # uses the speed from before it vanished
            if self.chasing and now - self.last_seen > self.chase_s:
                self.chasing = False          # chase found nothing, sweep from here
            if now - self.last_seen > 0.5:
                # Gone for more than a moment. Forget how fast it was moving.
                # (A single missed frame keeps the speed, so the lead does not stutter.)
                self._seen.clear()
                self.vel_pan = self.vel_tilt = 0.0
            # After a chase that found nothing, sweep right away. Without sweeping, hold the
            # chase spot for the usual wait before going back to center.
            chased_lately = self.chased or now - self.last_chase < 3.0
            give_up = self.chase_s if (chased_lately and self.sweep) else cfg.RETURN_AFTER_S
            if not self.chasing and now - self.last_seen > give_up:
                self.face_x = self.face_y = None
                if self.sweep:
                    self._sweep_step(pan_at_photo)
                else:
                    # Lost you for a while. Aim back at the middle (the mover glides there).
                    self.pan, self.tilt = float(cfg.PAN_CENTER), float(cfg.TILT_CENTER)

        self.pan = max(cfg.PAN_MIN, min(cfg.PAN_MAX, self.pan))
        self.tilt = max(cfg.TILT_MIN, min(cfg.TILT_MAX, self.tilt))
        return self.pan, self.tilt
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

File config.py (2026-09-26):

"""Every setting for the turret lives here. Change these, not the other files."""

# ---------------- camera (ArduCAM B0067) ----------------
SPI_BUS = 0
SPI_DEVICE = 0
SPI_SPEED_HZ = 8_000_000      # drops to 4 MHz by itself if frames keep failing
CS_GPIO = 17                  # physical pin 11
I2C_BUS = 1                   # pins 3 and 5

FRAME_SIZE = (320, 240)       # also allowed: (160, 120) or (640, 480)

# Picture orientation. The tracker detects a sideways or upside down camera by
# itself and prints the ROTATE value to put here, so it starts the right way up next time.
ROTATE = 0                    # 0, 90, 180 or 270
MIRROR = False                # True if text in the picture reads backwards

# ---------------- servos (SG90 on hardware PWM) ----------------
PWM_CHIP = None               # None = find it automatically, or e.g. "/sys/class/pwm/pwmchip0"
PAN_CHANNEL = 0               # GPIO12, physical pin 32
TILT_CHANNEL = 1              # GPIO13, physical pin 33

PULSE_MIN_US = 600            # pulse for 0 degrees
PULSE_MAX_US = 2400           # pulse for 180 degrees

PAN_CENTER = 90
PAN_MIN = 20                  # never go past these, so the wires cannot wind up
PAN_MAX = 160

TILT_CENTER = 90
TILT_MIN = 50                 # tighten these if the camera hits the frame
TILT_MAX = 130

# Direction. test_servos.py tells you what these should be.
PAN_DIR = -1                  # flip to 1 if the turret turns AWAY from your face
TILT_DIR = 1                  # flip to -1 if it tilts away from your face

# ---------------- motion ----------------
SERVO_SPEED = 550             # degrees per second. SG90 tops out around 600
SERVO_ACCEL = 4500            # how hard it speeds up and brakes. Lower if the Pi reboots when it moves

# ---------------- tracking ----------------
LEAD = 1.0                    # aim ahead of a moving face. 0 = off, 1 = normal
CORRECTION = 0.9              # share of the error fixed per frame. Lower if it swings past you
DEADZONE_X = 20               # pixels. Face this close to center while still = don't move
DEADZONE_Y = 15
RETURN_AFTER_S = 2.0          # seconds with no face before it starts searching

# ---------------- chasing a face that just left the picture ----------------
CHASE = True                  # face vanished at the edge or while moving fast = turn hard that way
CHASE_DEG = 20                # how far past the last sighting to aim (more if it was moving fast)
CHASE_S = 0.7                 # if the chase has not found it by then, start sweeping that way

# ---------------- searching when nobody is there ----------------
SWEEP = True                  # pan slowly side to side to find a face. False = wait at center
SWEEP_SPEED = 30              # degrees per second. Slower finds faces more reliably
SWEEP_MIN = 40                # left and right ends of the sweep (inside PAN_MIN / PAN_MAX)
SWEEP_MAX = 140
SWEEP_TILT = 90               # tilt angle while searching. Lower or raise to match face height

# ---------------- live view in a browser ----------------
STREAM_PORT = 8000

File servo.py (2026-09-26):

"""Servo control on the Pi 5's hardware PWM (GPIO12 and GPIO13).

Uses the kernel's /sys/class/pwm interface, which is rock steady timing.
Needs this line in /boot/firmware/config.txt (setup.sh adds it):
    dtoverlay=pwm-2chan,pin=12,func=4,pin2=13,func2=4
"""

import glob
import math
import os
import threading
import time
from collections import deque

SYSFS_PWM = "/sys/class/pwm"
PERIOD_NS = 20_000_000       # 50 Hz, what hobby servos expect


class ServoError(RuntimeError):
    pass


def _write(path, value):
    try:
        with open(path, "w") as f:
            f.write(str(value))
    except PermissionError:
        raise ServoError("No permission to control the servos without sudo.\n"
                         "Run this once:  bash install_boot.sh   then  sudo reboot")
    except OSError as e:
        raise ServoError("Could not write %s to %s: %s" % (value, path, e))


def _read(path):
    try:
        with open(path) as f:
            return f.read().strip()
    except OSError:
        return ""


def find_pwm_chip(base=SYSFS_PWM):
    """Find the PWM block that drives GPIO12/13 on a Pi 5.

    Its number changes between OS versions (pwmchip0, 1, 2...), so look for
    it by name instead. The one at ...98000.pwm is PWM0 on the RP1 chip.
    The one at ...9c000.pwm runs the cooling fan, never touch that.
    """
    chips = glob.glob(os.path.join(base, "pwmchip*"))
    chips.sort(key=lambda p: int(p.rsplit("pwmchip", 1)[1]))
    if not chips:
        raise ServoError(
            "No PWM found. Add  dtoverlay=pwm-2chan,pin=12,func=4,pin2=13,func2=4  "
            "to /boot/firmware/config.txt and reboot.")

    for c in chips:
        if "98000.pwm" in os.path.realpath(c):
            return c

    not_fan = [c for c in chips if "9c000.pwm" not in os.path.realpath(c)]
    if len(not_fan) == 1:
        return not_fan[0]

    listing = "\n".join("  %s -> %s" % (c, os.path.realpath(c)) for c in chips)
    if not not_fan:
        raise ServoError(
            "Only the fan PWM is present, so the servo overlay did not load.\n"
            "Check /boot/firmware/config.txt has the pwm-2chan line under [all], then reboot.\n" + listing)
    raise ServoError(
        "Found several PWM chips and could not tell which one drives GPIO12/13:\n"
        + listing + "\nSet PWM_CHIP in config.py to the right one.")


class Servo:
    def __init__(self, chip, channel, min_deg, max_deg,
                 pulse_min_us=600, pulse_max_us=2400):
        self.chip = chip
        self.channel = channel
        self.min_deg = min_deg
        self.max_deg = max_deg
        self.pulse_min_us = pulse_min_us
        self.pulse_max_us = pulse_max_us
        self.path = os.path.join(chip, "pwm%d" % channel)
        self.angle = None
        self.enabled = False

        if not os.path.isdir(self.path):
            _write(os.path.join(chip, "export"), channel)
            # The new folder takes a moment to appear and get its permissions.
            for _ in range(100):
                if os.access(os.path.join(self.path, "period"), os.W_OK):
                    break
                time.sleep(0.02)
            else:
                raise ServoError("pwm%d under %s never became writable.\n"
                                 "Run this once:  bash install_boot.sh   then  sudo reboot" % (channel, chip))

        # Duty to 0 first, in case an old duty is bigger than the new period.
        _write(os.path.join(self.path, "duty_cycle"), 0)
        _write(os.path.join(self.path, "period"), PERIOD_NS)

    def angle_to_ns(self, deg):
        us = self.pulse_min_us + (self.pulse_max_us - self.pulse_min_us) * deg / 180.0
        return int(round(us * 1000))

    def write(self, deg):
        """Move to an angle. Always kept inside min_deg..max_deg."""
        deg = max(self.min_deg, min(self.max_deg, float(deg)))
        deg = round(deg, 1)
        if deg == self.angle and self.enabled:
            return deg
        _write(os.path.join(self.path, "duty_cycle"), self.angle_to_ns(deg))
        if not self.enabled:
            _write(os.path.join(self.path, "enable"), 1)
            self.enabled = True
        self.angle = deg
        return deg

    def glide(self, target, step=1.0, delay=0.02):
        """Move slowly, one small step at a time. Kinder to the Pi's 5V rail."""
        if self.angle is None:
            return self.write(target)
        current = self.angle
        target = max(self.min_deg, min(self.max_deg, float(target)))
        while abs(target - current) > step:
            current += step if target > current else -step
            self.write(current)
            time.sleep(delay)
        return self.write(target)

    def release(self):
        """Stop sending pulses. The servo goes limp."""
        if self.enabled:
            try:
                _write(os.path.join(self.path, "enable"), 0)
            except ServoError:
                pass
            self.enabled = False


class _Axis:
    """One servo's smooth motion: speeds up, cruises, slows down, stops on target."""

    def __init__(self, servo, start, speed, accel):
        self.servo = servo
        self.pos = float(start)
        self.target = float(start)
        self.vel = 0.0
        self.speed = speed
        self.accel = accel
        self.limit = None       # a slower top speed for this move only (used by the search sweep)

    def step(self, dt):
        dist = self.target - self.pos
        if abs(dist) < 0.05 and abs(self.vel) < 5:
            self.pos, self.vel = self.target, 0.0
        else:
            # fastest speed that still lets it brake in time
            top = self.speed if self.limit is None else min(self.speed, self.limit)
            want = math.copysign(min(top, math.sqrt(2 * self.accel * abs(dist))), dist)
            dv = max(-self.accel * dt, min(self.accel * dt, want - self.vel))
            self.vel += dv
            new = self.pos + self.vel * dt
            if (self.target - new) * dist < 0:        # would pass the target, land on it
                new, self.vel = self.target, 0.0
            self.pos = new
        if self.servo is not None:
            self.servo.write(self.pos)
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

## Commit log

2026-09-26 Face tracking turret for Raspberry Pi 5 (v1.3.0)
    Pan and tilt turret using an ArduCAM Mini 2MP Plus over SPI/I2C and two SG90
    servos on hardware PWM. YuNet/SSD face detection, lead prediction for moving
    faces, 100 Hz smooth servo motion, chasing a head that flicks out of view,
    a slow search sweep when nobody is in view,
    auto orientation, live browser view, start on boot service with a turret
    command and doctor, and automatic tests with fake hardware.
2026-09-26 Add printed parts, build photo and clips
    hardware/ holds the three printed parts as .3mf to print and .step to edit.
    STEP because a mesh cannot be modified in any useful way: someone fitting this
    to their own robot needs to move a screw hole, not push triangles around. No
    STL, since 3mf carries its units and every current slicer reads it.
    The base has no floor. That keeps the servo and wiring reachable while building,
    and lets the turret bolt onto another robot's deck instead of carrying its own
    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
    [base.3mf, base.step, camera-attachment.3mf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]
2026-09-27 Retitle to Raspberry Pi Face Tracking Turret v1
2026-10-17 Add optional laser pointer (v1.4.0)
    New laser.py turns a GPIO pin on while a face is being tracked and off otherwise.
    Off by default (LASER_ENABLED). Eye safety comes from the mount, tilted down off
    the camera's own axis, not from the code; the laser never aims itself. Docs, tests
    and CHANGELOG updated to match.
